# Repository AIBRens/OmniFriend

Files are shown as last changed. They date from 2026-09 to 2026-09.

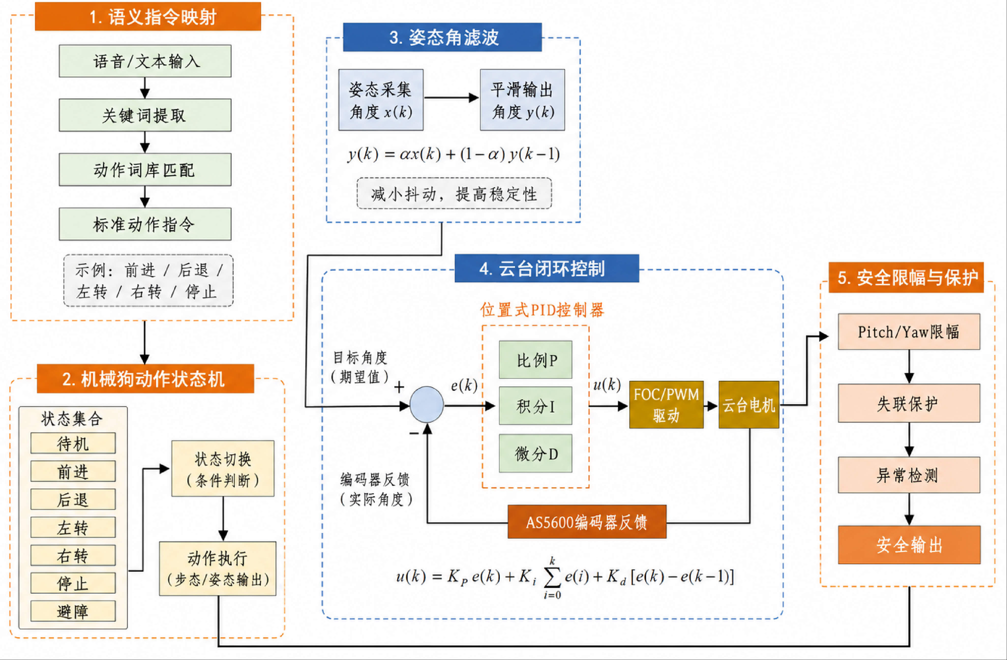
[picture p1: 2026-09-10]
images/18.png

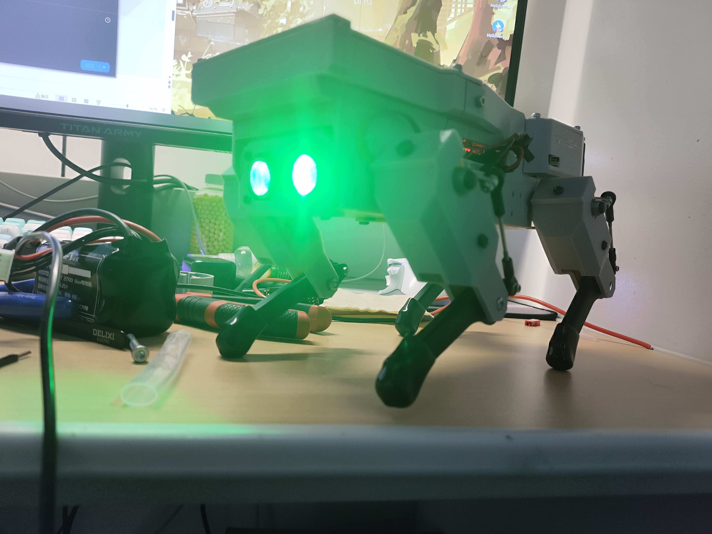
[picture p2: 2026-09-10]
images/20.jpg

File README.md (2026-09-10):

<div align="center">

<!-- <img src="docs/images/logo.png" width="150" alt="全域挚友 Logo"> -->

<h1>全域挚友——语义驱动的多场景微型AI 机械狗</h1>
<h3>机械狗，自动武器站与AI</h3>

<p>本项目基于ESP32与STM32开发。

项目包括：
一个微型的多功能机器狗底盘，并为其接入了云端大模型以实现语音交互。
一个作为机器狗任务模块范例的头瞄式水弹武器站。</p>

<p><b>| 总成本约 ¥1340 | 尺寸约 30cm 级 | 接入云端大模型 | 语音控制 | 公里级远程遥控 | 头部追踪 |</b></p>

<!-- 徽章区域 -->





<br>



</div>

## 📖 目录

- [项目速览](#项目速览)
- [总体设计方案分析](#总体设计方案分析)
- [主要部分实现原理](#主要部分实现原理)
- [硬件设计](#硬件设计)
- [软件设计](#软件设计)
- [调试与优化](#调试与优化)
- [团队分工](#团队分工)
- [局限与后续](#局限与后续)
- [免责声明](#免责声明)
- [致谢与参考](#致谢与参考)
- [器件列表](#器件列表)

## 🎯 项目速览

- **项目定位**：低成本、可扩展、自然交互的微型 AI 机械狗平台
- **核心能力**：语音对话、自然语言指令、四足运动、超声波测距、头戴姿态跟随、第一视角图传、水弹发射
- **硬件架构**：ESP32-S3（AI交互核心）+ ESP32（机械狗主控）+ STM32F103（头瞄端主控）+ STM32F405（武器站主控）
- **通信方式**：WiFi /蓝牙/ UART / NRF24L01 2.4G 无线/5.8G 无线
- **控制算法**：基于C/C++的动作状态机、一阶低通滤波、PID 位置闭环、FOC 无刷电机控制等

---

## ✨ 总体设计方案分析
	
&emsp;&emsp;本设计由机械狗运动系统、AI 交互系统、姿态采集系统、视频图传系统、云台炮塔跟随系统和无线通信系统组成。由于系统中同时存在多个单片机、多个传感器、多个执行机构以及软件上的算法和兼容协调问题，因此其控制特点体现在多模块协同、实时性要求较高、供电负载变化较大和调试过程较复杂几个方面。<br>
本系统的设计思路如下：<br>
1）通过ESP32-S3 语音开发板采集使用者语音，并利用WiFi 与云端大语言模型进行连接，使机械狗能够完成语音对话和自然语言指令解析，为其他功能的控制奠定基础以及实现与人的交流互动；<br>
2）通过机械狗本体ESP32 主控板接收ESP32-S3 下发的动作指令，结合MCP 服务，根据指令内容控制机械狗执行前进、后退、测距、开火等所具有的动作，统一了代码接口，新的硬件功能也容易加入进来；<br>
3）通过头戴式姿态采集端获取操作者头部姿态角，结合PID 算法与其他器件的控制，实现云台的平滑跟随，让武器端可以自由控制；<br>
4）通过3D 打印结构件和模块化安装方式，将机械狗本体与云台扩展模块结合起来，构成一个能够运动、交互和观察的综合平台，实现复杂连贯的功能。<br>

&emsp;&emsp;对于该项目而言，系统使用的核心模块较多，且执行机构包括多路总线舵机和两轴无刷云台电机，因此对供电性能有较高要求。机械狗在启动、转向或快速改变姿态时，舵机会产生较大的瞬时电流；云台电机在快速跟随时也需要稳定的电压输入。如果供电能力不足，可能会造成舵机复位、单片机掉电、无线通信中断或云台抖动等问题。因此，在硬件设计中需要对主控、舵机和云台部分进行分路供电，并保证共地连接可靠。<br>
&emsp;&emsp;控制性能上，机械狗本体动作需要具有一定的稳定性，语音指令下发后不能出现明显延迟或误动作；姿态跟随云台需要具有较好的实时性和连续性，避免因数据丢包、传感器漂移或控制参数不合适而出现跳变和震动。由于经济限制，本项目为可拓展与硬件升级的雏形，主要保证基本功能完整、动作过程稳定、模块之间通信可靠、整体结构便于展示和维护。<br>
&emsp;&emsp;
	
```mermaid
flowchart LR
  User[用户语音] --> S3[ESP32-S3 AI 交互端]
  S3 -->|WiFi| Cloud[云端 ASR / LLM / MCP]
  Cloud -->|结构化指令| S3
  S3 -->|UART| ESP32[机械狗本体 ESP32]
  ESP32 --> Servo[串行总线舵机]
  ESP32 --> Sonar[超声波测距]
  Head[头戴端 STM32F103 + ICM-20948] -->|NRF24L01| Turret[云台端 STM32F405]
  Turret --> Motor[4015 无刷电机 + AS5600]
  Cam[图传摄像头] --> Goggles[图传接收屏]
  S3 -->|UART| Turret
``` 
---

## 🏗️ 主要部分实现原理
1.**语义驱动控制**<br>
&emsp;&emsp;语义驱动控制部分主要完成“语音输入—语义理解—工具调用—指令生成—动作执行”的过程。与传统机器人依赖固定按键或预设命令不同，本课题希望使用者能够通过较自然的语言与机械狗进行交互。例如，当使用者说出“向前走一点”“停下来”“转过去看看”或“点点头”等口语化表达时，系统能够从语句中提取动作意图，并将其转换为机械狗底层可以识别和执行的控制命令，从而实现较自然的人机交互。<br>
&emsp;&emsp;本系统采用ESP32-S3 作为AI 语音交互终端。ESP32-S3 首先通过麦克风采集语音信号，并在本地完成唤醒、音频数据整理等基础处理。唤醒成功后，系统通过WiFi 将音频上传至云端服务，由语音识别模块完成语音转文本，再由大语言模型对文本语义进行理解。为了使模型不仅能够“听懂”用户的话，还能够进一步调用设备功能，系统在初始化联网时会通过MCP（ModelContext Protocol）机制，将已注册的工具信息同步给云端模型。这样，当模型识别到“点头”“前进”“左转”等动作意图时，就不只是返回普通文本回答，而是能够结合上下文判断当前请求属于某个可调用工具，并生成对应的结构化控制结果。<br>
&emsp;&emsp;执行过程中，云端模型根据MCP 提供的工具描述，将自然语言请求映射为底层动作参数，例如把“向前走”映射为FORWARD，把“向左转”映射为LEFT，把“停下”映射为STOP，把“点点头”映射为对应的动作编号或控制字段。ESP32-S3 接收到云端返回的结构化结果后，再通过UART 串口将指令发送给机械狗本体ESP32 主控。ESP32 主控收到数据后，首先对数据帧格式进行校验，然后根据动作字段切换机械狗当前的运动状态或执行对应动作。动作执行完成后，机械狗还可以将当前状态或异常信息回传给ESP32-S3，并通过扬声器或显示模块进行反馈，形成“语音输入—语义理解—动作执行—状态反馈”的闭环控制流程。<br>


2.**武器站云台跟随**<br>
&emsp;&emsp;云台的核心是姿态跟随（PID 算法），主要完成“头部姿态采集—无线数据传输—云台角度跟随”的过程。该模块采用分体式结构，头戴控制端由操作者佩戴，负责采集头部姿态；云台执行端安装在机械狗上方，负责根据接收到的角度数据完成方向跟随。该设计的优势在于操作方式直观，使用者不需要通过摇杆控制两个轴的角度，只需要转动头部即可改变云台指向。<br>
&emsp;&emsp;头戴端使用ICM-20948 九轴姿态传感器获取姿态信息。传感器内部包含陀螺仪、加速度计和磁力计，可以采集角速度、加速度和地磁方向等数据。通过I2C 接口读取传感器数据，姿态解算得到偏航角和俯仰角。为减少每次上电时初始佩戴姿态不同带来的误差，程序设置了零点校准步骤，即将系统启动后的初始头部方向作为基准方向，之后计算相对于基准方向的角度变化。<br>
&emsp;&emsp;姿态数据经过处理后，由NRF24L01 无线模块发送至云台端。该模块工作在2.4G 频段，体积小、成本低、通信速度较快，适合在课程设计模型中实现短距离无线数据传输。为了提高通信稳定性，发送端将角度数据打包成固定长度数据帧，接收端对帧头、帧尾和数据范围进行判断，避免错误数据直接进入控制环节。云台执行端使用STM32F405RGT6 作为主控，结合无刷云台电机和AS5600 磁编码器实现闭环控制。磁编码器能够提供电机轴的角度反馈，主控将目标角度与实际角度进行比较，根据误差输出控制量，使电机逐渐转动到目标位置。与普通舵机相比，无刷云台电机运行更平滑，机械回差较小，更适合完成连续的姿态跟随演示。<br>

3.**整体方案**<br>
&emsp;&emsp;本项目采用“机械狗主体+ 功能扩展模块”的总体设计方案。机械狗本体作为系统的主要移动平台，负责完成运动执行和模块承载；ESP32-S3 AI 交互模块作为上层控制入口，负责语音采集、网络连接、云端转发、语义解析结果接收以及语音反馈；头戴端作为姿态输入设备，负责采集操作者头部的偏航角和俯仰角，图传设备和头戴端可合二为一；云台端作为扩展执行模块，负责根据姿态数据完成两轴跟随和观察方向调整。各部分既可以独立调试，又能够通过串口通信、无线通信和机械结构连接组合成完整系统，从而形成一个具有语音交互、运动控制和姿态跟随能力的微型AI 机械狗平台。<br>
&emsp;&emsp;供电上，机械狗本体采用3S 锂电池作为主要动力来源，并通过降压模块分别为主控板、舵机和外围传感器供电。由于串行总线舵机在启动、转向和姿态调整时会产生较大的瞬时电流，如果主控和舵机共用不稳定电源，容易导致单片机复位或通信异常，因此本项目在设计时将主控供电与舵机供电分开处理，并保证各模块之间可靠共地。ESP32-S3 语音模块采用独立稳压供电，以保证WiFi 通信、语音采集和音频播放过程的稳定性。云台模块则采用独立主控和独立供电方案，使其能够在不影响机械狗运动系统的情况下单独完成调试与优化。<br>
&emsp;&emsp;通信上，ESP32-S3 与机械狗主控之间采用UART 串口通信。ESP32-S3 在接收到云端模型返回的结构化动作指令后，通过TX/RX 引脚将指令发送给机械狗主控，机械狗主控再根据指令字段调用对应的动作函数。该方式连接简单、延迟较低、调试直观，适合课程设计中的功能验证。头戴端与云台端之间采用NRF24L01 无线通信，避免操作者与机械狗之间受到线缆限制。云台端内部通过I2C 接口读取AS5600 磁编码器的角度反馈，并结合无刷电机驱动与FOC 控制算法实现位置闭环，使云台能够较平滑地跟随操作者头部姿态变化。<br>
&emsp;&emsp;结构设计上，机械狗主体和扩展外壳主要采用3D 打印方式制作。该方式成本较低，修改灵活，便于根据PCB 尺寸、屏幕位置、接口开孔和线束走向进行多次调整。云台模块通过螺钉固定在机械狗背部扩展位置，与本体之间保持相对独立，后期可以根据需要拆下或替换为其他功能模块，如机械臂、照明模块、红外测温模块或环境检测模块。这样的设计体现了课程设计中“先实现基础功能，再进行模块扩展”的思路，也为后续进一步集成视觉识别、环境感知和自主任务执行提供了硬件基础。<br>


----------

## 🔧 硬件设计
&emsp;&emsp;硬件设计是本项目能够实现功能的基础，是作品的骨架和支撑。根据系统功能划分，硬件部分主要包括机械狗本体硬件、AI 语音交互硬件、头戴姿态采集硬件、图传硬件、云台执行硬件、无线通信硬件和供电硬件。器件选型时主要考虑成本、体积、性能、资料完整程度以及调试难度，尽量选择常用、资料较多、便于购买和维护的模块。<br>

1.**机械狗本体设计**<br>
&emsp;&emsp;机械狗本体是整个系统的移动平台，主要由3D 打印结构件、舵机、主控板、电池、传感器以及连接线束组成。机械结构部分采用3D 打印方式制作，能够根据舵机尺寸和安装孔位进行灵活设计。机身中部预留电池仓和控制板安装位置，四条腿分别由多个舵机构成，通过舵机角度变化实现腿部摆动和支撑。<br>
&emsp;&emsp;机械狗运动主控采用ESP32 控制板。ESP32 资料丰富，外设接口较多，并支持串口通信、定时器控制、I2C 传感器读取和动作状态机运行等功能，能够满足机械狗本体运动控制需求。主控板接收来自ESP32-S3 的动作指令后，根据预设步态表或运动函数控制各关节舵机转动，实现前进、后退、左转、右转和停止等基本运动动作。<br>


&emsp;&emsp;执行机构采用串行总线舵机。总线舵机相比普通PWM 舵机具有接线简单、控制精度较高、可读取反馈信息等优点。多个舵机可以通过同一条总线串联，减少机身内部线束数量，使机械狗内部结构更加整洁。调试时可以分别设定每个舵机的ID 和初始角度，保证四条腿在初始状态下姿态一致。<br>
&emsp;&emsp;AI 语音交互硬件以ESP32-S3 开发板为核心。ESP32-S3 集成WiFi 和蓝牙功能，并具有较强的音频处理和边缘计算能力，适合用于语音采集、网络通信和简单的人机交互任务。语音输入部分采用I2S 数字麦克风，能够获得较清晰的语音信号；语音输出部分采用功放模块和小型扬声器，用于播放系统回复和动作反馈。自主画电路板将芯片与一些就基础模块集成便于后续的模块化开发。<br>


&emsp;&emsp;环境感知方面，机械狗前部设置超声波测距模块，用于检测前方障碍物距离。当机械狗在前进过程中检测到距离过近时，主控可以执行停止或转向动作，避免直接碰撞。机身内部还可以安装MPU6050 等惯性测量模块，用于获取机体俯仰等变化，为姿态稳定和运动补偿提供数据基础。<br>


2.**头戴控制端设计**<br>
&emsp;&emsp;头戴控制端的设计重点是轻量化、低功耗和佩戴方便。该端主要由STM32F103C8T6 最小系统板、ICM-20948 九轴姿态传感器、NRF24L01 无线模块、电池和电源升压模块组成。各模块体积较小，可以安装在头戴支架或小型盒体中，使用时由操作者佩戴在头部。STM32F103C8T6 负责读取姿态传感器数据，并将数据进行滤波、零点校准和打包发送。ICM-20948 能够输出加速度、角速度和磁场数据，为姿态解算提供基础。由于传感器原始数据存在噪声和漂移，程序中需要对数据进行简单滤波，并设置启动校准过程，使系统在不同佩戴角度下都能获得相对稳定的姿态变化量。<br>
&emsp;&emsp;无线通信模块采用NRF24L01+PA+LNA。该模块带有功放和低噪声放大电路，通信距离和抗干扰能力优于普通NRF24L01 模块。头戴端只需要将姿态角数据单向发送至云台端，因此通信协议可以设计得较为简单，只需保证帧格式固定、数据范围合理即可。



| 器件类别 | 具体型号 | 功能说明 |
| :--- | :--- | :--- |
| 主控芯片 | STM32F103C8T6 | 负责传感器读取、姿态角处理和无线发送 |
| 姿态传感器 | ICM-20948 | 采集头部加速度、角速度和磁场信息 |
| 无线通信 | NRF24L01+PA+LNA | 将姿态角数据发送至云台执行端 |
| 供电模块 | 18650 电池及升压板 | 为头戴端提供独立电源 |
| 结构支架 | 3D 打印头戴支架 | 固定传感器和主控，方便佩戴与调试 |

3.**武器站设计**<br>
&emsp;&emsp;武器站部分的硬件均为自主建模与3D 打印，主要由头戴控制端和云台执行端组成。头戴控制端负责采集操作者头部姿态，云台执行端负责根据姿态数据完成方向跟随。该部分采用独立供电、独立通信和独立控制方式，不影响机械狗本体的基本运动功能。该端主要由STM32F405RGT6主控、无刷云台电机、FOC 驱动板、AS5600 磁编码器、NRF24L01 接收模块和图传模块组成。STM32F405RGT6 具有较高主频和浮点运算能力，能够满足姿态数据解析、编码器读取和闭环控制计算等需求。<br>
&emsp;&emsp;执行电机选用4015 无刷云台电机。该类电机具有转动平滑、噪声较低、力矩输出连续等优点，适合用于摄像头云台和姿态跟随平台。为了获得电机实际角度，系统在电机轴端安装AS5600磁编码器。AS5600 能够输出绝对角度信息，主控通过I2C 接口读取该角度，与目标角度进行比较后输出控制量。<br>
&emsp;&emsp;云台端还搭载5.8G 图传模块（可分离），用于传输第一视角画面。图传系统能够使操作者从云台视角观察前方环境，与头部姿态跟随功能结合后，可以形成较直观的“看向哪里，画面转向哪里”的演示效果。由于图传模块对电源稳定性有一定要求，因此在供电设计中应与电机驱动部分做好隔离和滤波，减少电机动作对画面的干扰。<br>


| 器件类别 | 具体型号 | 功能说明 |
| :--- | :--- | :--- |
| 主控芯片 | STM32F405RGT6 | 负责无线接收、数据解析和云台闭环控制 |
| 无刷驱动 | 灯哥开源 V3P 驱动 | 驱动无刷云台电机，实现 FOC 控制 |
| 执行电机 | 4015 无刷云台电机 | 完成云台偏航和俯仰两个方向的转动 |
| 位置编码 | AS5600 磁编码器 | 提供电机轴角度反馈，构成闭环控制 |
| 视频图传 | 5.8G 图传模块 | 传输第一视角画面，方便远程观察演示 |
| 供电模块 | 降压稳压模块 | 为主控、驱动和图传模块提供稳定电压 |

----------

## 💻 软件设计
   &emsp;&emsp;软件部分决定了各个硬件模块能否稳定协同工作。根据功能划分，软件设计主要包括机械狗AI 交互、头戴端控制、云台武器端控制以及无线通信。软件整体采用分层设计思想，上层负责语义交互和任务判断，下层负责具体动作控制和执行机构驱动，两者分别完成用通信协议连接起来。<br>
    1. **AI 交互**<br>
&emsp;&emsp;AI 交互部分是本课题智能的核心。接入AI 小智大模型到ESP32-S3 上，设置MCP 服务，语言交互以及调用控制已有的所有功能。<br>
&emsp;&emsp;程序运行后，ESP32-S3 首先进入待唤醒状态，持续监听外部声音。当检测到设定唤醒词后，系统开始录制语音，并将音频数据整理为云端接口可以接收的格式。音频上传后，云端服务完成语音识别和语义理解，并返回对应文本或结构化指令。对于聊天类问题，ESP32-S3 直接将返回内容通过语音合成模块播放出来；对于动作类指令，ESP32-S3 则提取其中的动作字段，并通过串口发送给机械狗本体ESP32 主控。<br>
&emsp;&emsp;为了减少自然语言带来的不确定性，程序中预先设置了动作关键词和标准指令之间的对应关系。例如，“前进、往前走、向前移动”均对应前进指令；“停下、停止、别动”均对应停止指令；“左转、向左看、往左转”均对应左转指令。这样可以提高识别成功率，也可以避免大语言模型返回过长文本导致底层主控难以解析。<br>
&emsp;&emsp;ESP32-S3 与机械狗本体ESP32 之间采用简单串口协议通信。每一条动作指令由帧头、指令字、参数位和校验位组成。帧头用于判断一条数据的开始，指令字用于表示动作类型，参数位用于表示持续时间或动作幅度，校验位用于判断传输是否正确。机械狗本体ESP32 接收到数据后，根据指令内容进入相应状态，并在动作完成后返回执行结果。ESP32-S3 再根据返回结果进行语音提示，如“已前进”“已停止”“前方有障碍”等。<br>

2.**头戴端控制**<br>
&emsp;&emsp;头戴端控制部分负责完成姿态数据采集、姿态解算和无线发送。程序启动后，STM32F103C8T6首先完成ICM-20948 和NRF24L01 模块初始化，通过ICM-20948 获取头部加速度、角速度等数据，并利用内部DMP 完成姿态解算，将四元数转换为偏航角和俯仰角。由于不同操作者佩戴角度存在差异，系统启动时会进行零点校准，将当前状态作为参考方向，后续只计算头部相对变化量。<br>
&emsp;&emsp;处理后的姿态数据经过简单滤波后，通过NRF24L01 无线发送至云台端。为了降低通信延迟，数据帧仅包含偏航角、俯仰角和校验信息，并采用固定格式传输。当出现异常数据或通信中断时，程序会进行数据判断，避免错误角度直接影响云台运动，提高系统稳定性。<br>

3.**云台武器端控制**<br>
&emsp;&emsp;云台武器端负责姿态数据接收、角度解析和闭环控制。STM32F405RGT6 接收到头戴端发送的数据后，对目标角度进行解析和滤波，并结合AS5600 磁编码器获取电机实际角度，通过比较目标角度与反馈角度之间的误差，实现云台位置闭环控制。<br>
&emsp;&emsp;执行机构采用两台4015 无刷云台电机，通过FOC 算法控制偏航和俯仰两个方向转动。相比普通舵机，无刷电机具有运行平滑、响应速度快等特点，更适合连续姿态跟随。控制过程中加入PID 调节和角度限幅，减少电机震荡和机械冲击，使云台能够稳定完成“人看哪里，云台转向哪里”的跟随效果。<br>
&emsp;&emsp;其中武器的开火设定为高电平下连续开火，也就是通过控制电平可以实现全自动开火，收到的云台芯片指令即为简单的电平信号。<br>
4.**无线通信**<br>
&emsp;&emsp;无线通信部分主要用于头戴端和云台端之间的姿态数据传输。由于姿态跟随对实时性有一定要求，因此数据帧需要尽量简洁，通信过程需要尽量稳定。头戴端将偏航角和俯仰角转化为整型数据后发送，云台端接收到数据后再恢复为角度值，并作为云台控制目标。<br>
&emsp;&emsp;头戴端程序的主要流程为：初始化STM32 外设、初始化ICM-20948、初始化NRF24L01、进行姿态零点校准、循环读取姿态数据、进行滤波处理、打包发送数据。由于头部姿态变化较为连续，发送数据时不需要包含过多信息，只需发送偏航角、俯仰角和简单校验即可，这些数据发送给云台端。<br>
&emsp;&emsp;云台端程序的主要流程为：初始化STM32F405、初始化NRF24L01、初始化AS5600 编码器、初始化FOC 驱动参数、等待接收姿态数据、判断数据是否有效、对目标角度进行限幅和滤波、执行闭环控制。若一段时间内未接收到头戴端传来的有效数据，云台端会保持当前角度或缓慢回到安全位置，避免因通信中断造成异常动作。在实际调试中，无线通信容易受到实验室WiFi、蓝牙设备和电源噪声甚至电磁干扰等影响。<br>
&emsp;&emsp;为提高系统稳定性，程序中加入了数据有效性判断和异常跳变抑制。当接收到的数据超出合理范围，或相邻两帧角度变化过大时，接收端不会立即执行该数据，而是将其视为异常帧丢弃。这样可以减少丢包或误码造成的云台突然跳动。<br>

5.**算法设计**<br>
&emsp;&emsp;算法主要包括语义指令映射、机械狗动作状态机、姿态角滤波算法、云台PID 闭环控制算法和安全限幅算法。虽然这些都不是复杂的算法，但它们直接影响系统运行效果，是课程设计中非常重要的部分。<br>
1）语义指令映射算法。语音识别得到的文本往往不是固定格式，因此需要将自然语言中的关键词提取出来，并映射成ESP32 能够识别的标准动作。程序中建立动作词库，将相近表达归为同一类动作。例如“向前走”“前进一下”“往前移动”都映射为FORWARD；“停下”“暂停”“不要动”都映射为STOP。通过这种方式，系统能够适应一定程度的口语表达。<br>
2）机械狗动作状态机。机械狗的动作不应由单个瞬时指令直接控制，而应由状态机进行管理。系统设置待机、前进、后退、左转、右转、避障、停止等状态。每个状态对应一组舵机角度变化规律。当主控接收到新指令时，先判断当前状态是否允许切换，再执行对应动作。这样可以避免机械狗在动作未完成时突然切换导致姿态不稳。<br>
3）姿态角滤波算法。姿态传感器采集到的数据会受到手部抖动、传感器噪声和零漂影响，如果直接用于云台控制，会导致云台持续轻微抖动。因此程序中采用一阶低通滤波对目标角度进行平滑处理，其形式如下：

$$
y(k) = \alpha x(k) + (1-\alpha)y(k-1) \quad (1)
$$

式中，\(x(k)\) 为当前采集角度，\(y(k)\) 为滤波后角度，\(\alpha\) 为滤波系数。\(\alpha\) 越大，响应越快但抖动越明显；\(\alpha\) 越小，输出越平滑但跟随会变慢。实际调试时需要根据云台响应情况选择合适参数。

4）云台闭环控制算法。云台控制采用位置闭环思想，将目标角度与编码器反馈角度进行比较，根据误差输出控制量。基本 PID 控制公式如下：

$$
u(k) = K_p e(k) + K_i \sum_{j=0}^{k} e(j) + K_d \big[e(k)-e(k-1)\big] \quad (2)
$$

其中，\(e(k)\) 表示当前角度误差，\(K_p\)、\(K_i\)、\(K_d\) 分别为比例、积分和微分系数。比例项决定系统响应速度，积分项用于消除稳态误差，微分项用于抑制变化过快带来的超调。在本项目中，为了减少云台抖动，积分项不宜设置过大，同时需要配合死区控制。

5）安全限幅算法。为了避免云台转动角度过大造成线材缠绕或结构干涉，程序中设置了角度限幅。当目标角度超过最大允许范围时，系统自动将其限制在边界值内。同时，当检测到连续异常数据或通信中断时，云台不继续执行新目标，而是保持当前位置。该算法虽然简单，但能有效提高系统安全性和稳定性。



----------
## 🐛 调试与优化
&emsp;&emsp;系统调试过程中，团队主要遇到了语音识别不稳定、舵机动作不协调、无线通信丢包、云台零点抖动和机械结构干涉等问题。通过逐步排查和修改程序，系统运行稳定性得到明显改善。<br>
1）本地MCP 指令解析问题。初期测试时，ESP32-S3 能够完成语音识别，但大语言模型返回的内容较长，有时包含解释性文字，导致机械狗本体ESP32 无法直接识别动作指令。针对该问题，团队在ESP32-S3 端增加了关键词提取和指令映射步骤，只将标准动作指令发送给ESP32，而不是将完整回复发送到底层主控。另外，流行的几种MCP 方案均为两芯片连接至同局域网的方案，这种办法不稳定，并且实现起来复杂，要配置各种环境，于是本作品采取本地的MCP 方案，让大模型对功能的调用执行通过物理跳线实现。这样既保留了对话功能，又保证了动作控制的可靠性。<br>
2）机械狗站立姿态偏斜问题。在本体调试过程中，机械狗有时会出现站立不平稳或行走时向一侧偏移的现象。经过检查发现，主要原因是部分舵机初始角度不一致，且左右腿结构安装存在细小误差。解决方法是重新标定每个舵机中位值，并在程序中为不同关节设置角度补偿。调整后，机械狗站立姿态更加稳定，前进时偏移现象有所减轻。<br>
3）供电瞬态压降问题。机械狗多个舵机同时动作时，电流需求会瞬间增大，曾出现主控板复位和语音模块重启的情况。针对该问题，团队将主控供电和舵机供电分开，增加降压模块余量，并在电源输入端增加滤波电容。分路供电后，机械狗连续动作时系统稳定性明显提高。<br>
4）无线通信丢包与角度跳变问题。在实验室环境中，NRF24L01 偶尔会受到其他2.4G 设备影响，导致接收端数据短时间异常。若异常数据直接用于控制，云台会出现突然跳动。针对该问题，程序中加入数据范围判断和角度变化率判断。当单帧数据变化过大时，系统先判断为异常帧并丢弃；只有连续多帧数据变化趋势一致时，才认为操作者确实进行了快速转头动作。<br>
5）云台零点微震问题。静态测试中，当操作者头部保持不动时，云台仍可能出现轻微抖动。分析原因主要是姿态传感器存在微小噪声，编码器反馈也有一定波动，导致控制器不断进行小幅修正。解决方法是在角度误差较小时加入控制死区，当误差小于设定阈值时，控制器不再输出明显修正量，同时适当降低PID 参数中的比例和积分系数，使云台在静止状态下更加平稳。<br>
6）机械结构重心与干涉问题。云台在俯仰角度较大时，部分结构件可能与机械狗背部平台或图传摄像头线材发生干涉。针对该问题，一方面在程序中加入角度限幅，限制云台最大俯仰角和偏航角；另一方面对3D 打印支架进行修改，增加线材固定点和转动空间。经过调整后，云台在正常演示角度内能够较顺畅地转动。<br>
经过多轮调试后，系统基本实现了预定功能。机械狗可以在平整地面完成基本移动动作，ESP32-S3 可以完成语音交互和动作指令下发，头戴端可以将姿态变化无线发送至云台端，云台能够跟随操作者头部方向进行转动。虽然系统距离成熟产品还有一定差距，但作为小型项目，已经较完整地体现了智能交互、嵌入式控制和模块化机器人的设计思路。<br>


## 👥 团队分工

&emsp;&emsp;我：部件选型与采购；硬件设计与建模；PCB设计；多单片机协作的设计与开发；滤波与PID算法的开发；与武器站、头戴端相关程序的编写与调试；硬件装配与测试。<br>
&emsp;&emsp;我的另一位队友：云端大模型与各模块的接入与通信工作；大模型的配置、提示词处理与工具调用；配置UART通信；与AI、超声波测距相关程序的编写。<br>

----------

## 🔭 局限与后续

&emsp;&emsp;对于本项目，我们已经实现了语音交互、机械狗基础动作、姿态跟随、武器全自动开火、无线通信等功能，具有多方协调与初具只能的优点，但距离更加智能、稳定的机械狗仍有不少可以继续改进的地方。<br>
首先，机械狗运动稳定性仍有提升空间。当前机械狗能够完成基本运动，但在负载增加、地面不平或连续动作时，机身姿态可能不稳。后续可以引入与优化平衡算法，增加机身姿态反馈，使机械狗能够根据外部反馈数据自动调整腿部动作，提高运动过程中的稳定性。<br>
&emsp;&emsp;其次，AI 交互功能对网络环境仍有一定依赖。当前语音识别和语义理解主要依靠云端服务完成，当网络状态不稳定或距离网源较时，系统响应速度和交互连续性会受到影响。后续可以尝试引入边缘计算小程序，在本地部署轻量化语音识别模型或小型语言模型，使机械狗在离线或弱网环境下也能完成基础交互。<br>
&emsp;&emsp;再次，云台跟随精度和稳定性还可以继续优化。当前云台能够跟随头部姿态变化，但在快速转头或机械狗运动过程中，仍可能出现滞后和抖动。后续可以在滤波算法、控制死区和机身运动补偿方面继续改进，或者引入串级PID，实现更精细的反馈闭环控制，使云台在动态情况等也能保持较稳定。<br>
&emsp;&emsp;此外，视觉系统后续可以增加图像处理模块，结合YOLO、OpenMV 色块识别或轻量化目标检测算法，实现目标识别、人体识别、路线识别和自动巡检等功能。这样机械狗就不只是按照语音指令执行动作，而是能够根据环境信息做出更主动的判断，朝着具身智能迈进一步。<br>
&emsp;&emsp;最后，也是最重要的两个关联点，目前很大的不足是硬件性能不够以及衍生的结构设计缺陷，机械狗主体是ESP32，运算和内存性能都较低，支撑不了较强的处理算法、实时反馈的运动控制，若非原结构与集成的限制，可改用树莓派等板子，利用强化学习而非固定代码让机械狗自己运动以及部署深度学习视觉处理，此时也可以在离线模式下进行AI 交互，而机身与低扭矩的舵机让机械狗承载能力不足，让拓展性受到了限制。<br>

----------

## ⚠️ 免责声明

本项目为课程设计与学习交流用途，发射模块仅用于水弹娱乐演示，安全无害，比动能小于1.8J/cm²。请勿改装为危险装置，请勿对准人或动物，操作时请佩戴护目镜并遵守当地法律法规。<br>

----------

## 🙏 致谢与参考

-   我的另一位团队成员<br>
-   课程指导老师，他一语点醒梦中人，告诉我电机运行会产生电磁干扰，可能是导致I2C总线死锁的原因<br>
- 帮我干活的Gemini，GPT，deepseek和豆包<br>
-  小智AI.Dev<br>
-   Espressif ESP32 / ESP32-S3 官方资料<br>
-   SimpleFOC 开源项目<br>
-   SparkFun ICM-20948 库<br>
-   Anthropic MCP 协议<br>

**参考文献**：<br>
[1] 侯焱彬, 杨永辉, 李志刚, 等. 面向工业气体安全监控的智能巡检机械狗[J]. 工业控制计算机,2026,39(5):63-64+67.<br>
[2] 夏立伟. 四足机械狗在化工安全领域的应用[J]. 石化技术,2025,32(6):348-350.<br>
[3] 潘杰. 基于MCP 智能体架构的“本地-云端大模型协同”优化方案研究[J]. 电脑编程技巧与维护,2026,(2):3-6+11.<br>
[4] 夏峰. 头盔瞄准系统的人机交互研究及设计[D]. 哈尔滨工业大学,2013.<br>
[5] 王云龙, 赵正媛, 吴志林, 等. 轻型遥控武器站多工况力学特性及射击扰动[J]. 兵工学报,2025,46(10):366-380.<br>
[6] 郭丽君, 周文杰, 刘杰, 等. 一种超轻型遥控武器站的设计[J]. 电脑与信息技术,2025,33(4):122-127.<br>
[7] Anthropic. Model Context Protocol Specification[EB/OL]. (2024-11-25)[2026-07-05].https://modelcontextprotocol.io/specification.<br>
[8] Espressif Systems. ESP32 Series Datasheet and ESP32-S3 Series Datasheet[EB/OL]. [2026-07-05]. https://www.espressif.com/en/support/documents/technical-documents.<br>
[9] Nordic Semiconductor. nRF24L01+ Single Chip 2.4GHz Transceiver Product Specificationv1.0[EB/OL]. Nordic Semiconductor, 2008.<br>
[10] TDK InvenSense. ICM-20948 Datasheet[EB/OL]. TDK Corporation, 2016.<br>
[11] Redmon J, Divvala S, Girshick R, Farhadi A. You Only Look Once: Unified, Real-TimeObject Detection[C]//Proceedings of the IEEE Conference on Computer Vision and PatternRecognition. 2016:779-788.<br>
[12] Liao Q, Zhang Z, Ke W, et al. Review of Quadruped Robots for Dynamic Locomotion[J/OL]. arXiv preprint arXiv:2005.11134, 2020.<br>
[13] Mudalige N D W, Van K D, Han J, et al. HyperDog: An Open-Source Quadruped RobotPlatform Based on ROS2 and micro-ROS[J/OL]. arXiv preprint arXiv:2209.09171, 2022.<br>

----------
## 📦 器件列表

| 应用模块 | 器材名称与规格 | 价格（元） |
| :--- | :--- | :--- |
| 云台主控 | STM32F405RGT6 × 2 | 79.60 |
| 云台转接 | DengFOC STM32 转接板 | 40.00 |
| 供弹结构 | 硅胶管 | 3.16 |
| 图传系统 | 图传线 | 12.90 |
| 调试工具 | CH340G 串口调试器 | 6.80 |
| 接口转接 | Type-C 垂直转接头 | 13.50 |
| 无刷驱动 | 灯哥开源双路无刷电机控制板 | 84.00 |
| 发射控制 | 大功率 MOS 管 | 7.26 |
| 云台电机 | 4015 直流无刷电机 × 2 | 231.28 |
| 烧录调试 | ST-Link 烧录器 | 6.79 |
| 云台结构 | 铝合金底座转盘轴承 | 22.70 |
| 供电系统 | 降压板 | 34.80 |
| 图传系统 | 5.8G 天线 | 5.50 |
| 散热系统 | 散热风扇 | 3.25 |
| 电源接口 | XT30 接头 | 13.50 |
| 辅助瞄准 | 激光头 | 11.70 |
| 供电系统 | 电源分路器 | 53.00 |
| 连接材料 | 导线 | 4.88 |
| 云台结构 | 光轴 | 6.08 |
| 姿态采集 | ICM20948 九轴陀螺仪 | 43.00 |
| 发射耗材 | 高抗压加硬水弹 | 3.69 |
| PCB 辅料 | 排针排母、开关、PCB 微型元件等 | 24.85 |
| 无线通信 | NRF24L01+LAN 无线模块 × 2 | 17.92 |
| 紧固件 | 螺丝 | 11.94 |
| 结构制作 | 3D 打印耗材 | 29.00 |
| 图传系统 | 2W 图传 + 1500 线摄像头 | 170.00 |
| 图传接收 | 图传眼罩接收屏 | 289.00 |
| 图传系统 | 图传天线 | 22.46 |
| 发射机构 | 水弹波箱 | 46.40 |
| 发射机构 | 弹匣 | 19.00 |
| 外观装饰 | 模型水贴 | 13.00 |
| 云台结构 | 薄壁轴承 × 4 | 8.84 |
| **项目总造价** | | **1339.80** |

## 📄 License

MIT License，详见 [LICENSE](https://license/)。

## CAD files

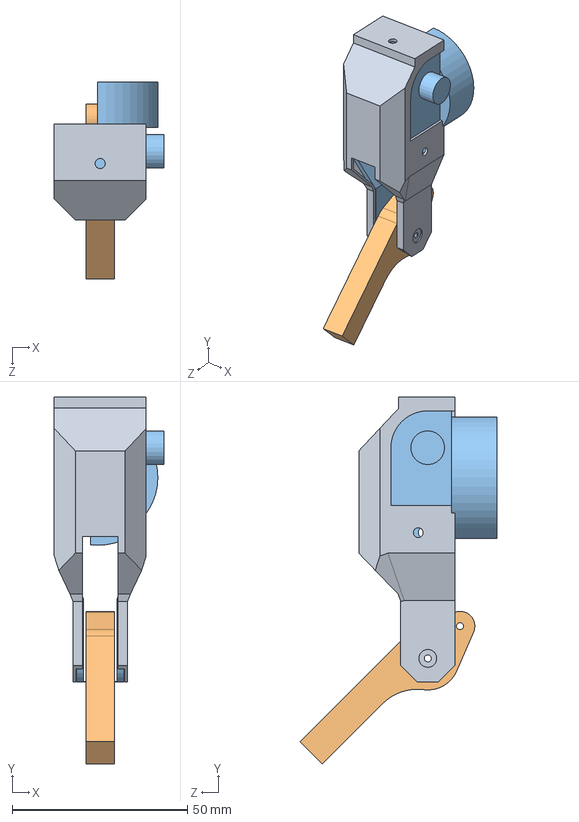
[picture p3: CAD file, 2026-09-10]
DOGV2.0/腿.SLDASM
31.2 x 104.6 x 56.1 mm
大腿
小腿
腿外壳

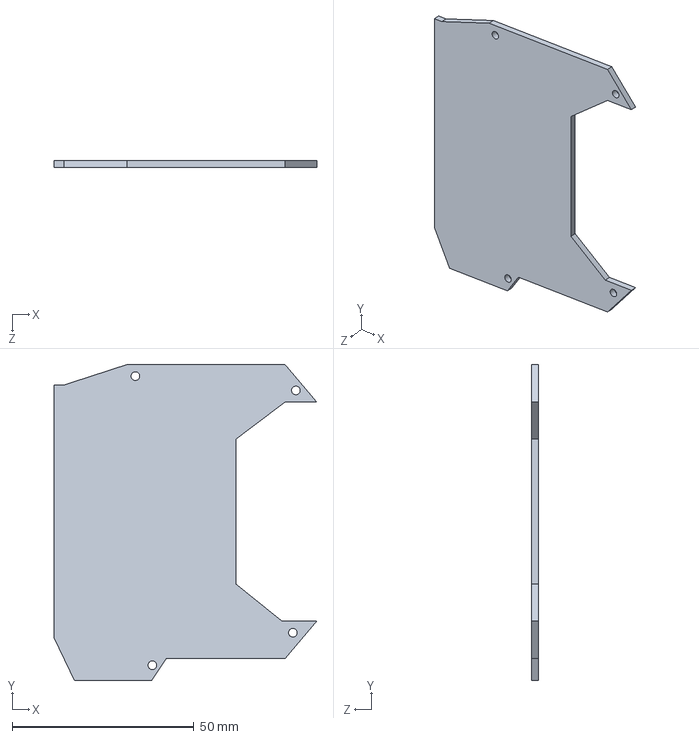
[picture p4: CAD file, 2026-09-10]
DOGV2.0/后上盖.SLDPRT
72.3 x 87.0 x 2.00 mm

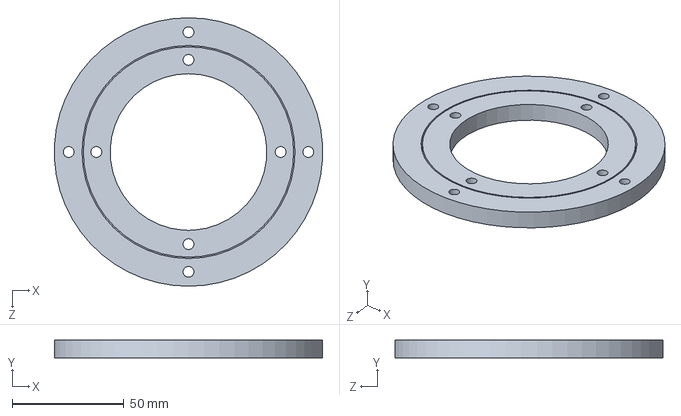
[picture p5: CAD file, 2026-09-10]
吕布骑狗V2.0/转盘.SLDPRT
119.8 x 8.00 x 120.0 mm

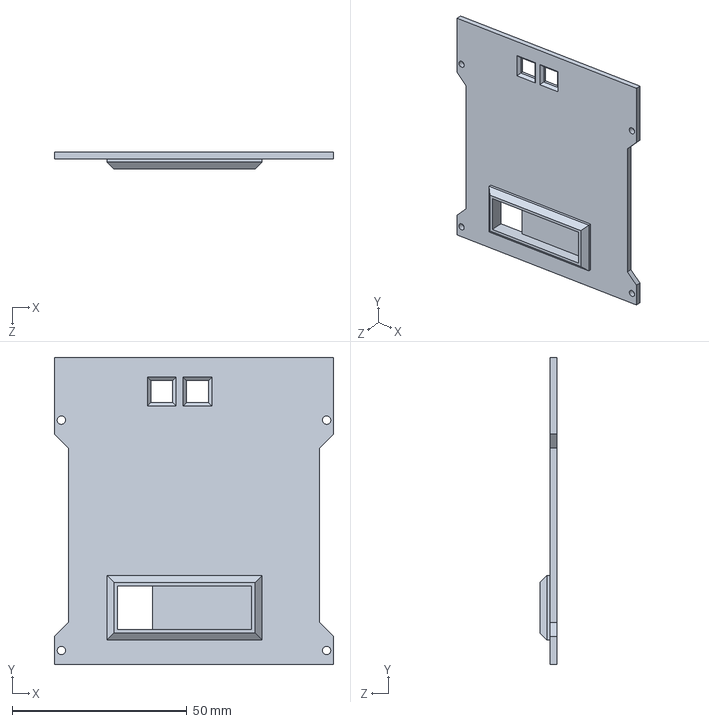
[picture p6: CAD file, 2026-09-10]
DOGV2.0/前盖.SLDPRT
79.8 x 87.7 x 5.00 mm

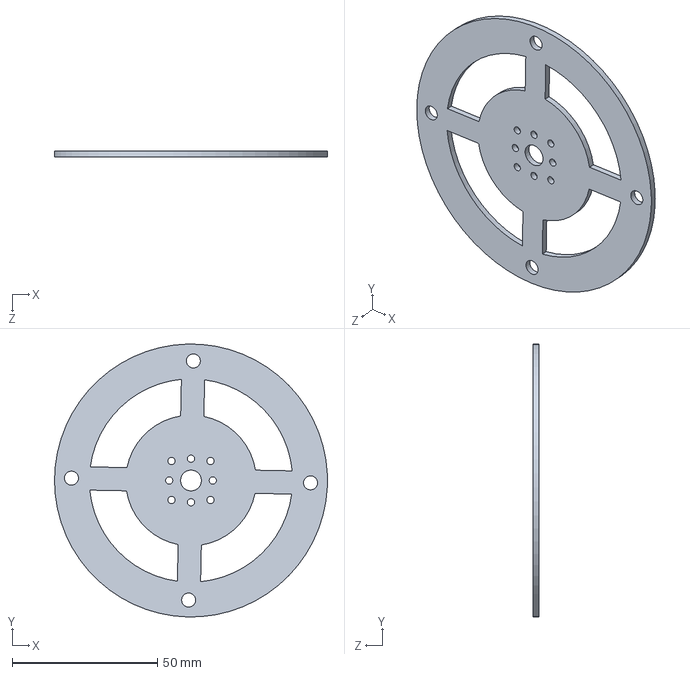
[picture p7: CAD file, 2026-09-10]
吕布骑狗V2.0/底座垫片.SLDPRT
94.0 x 94.0 x 2.00 mm

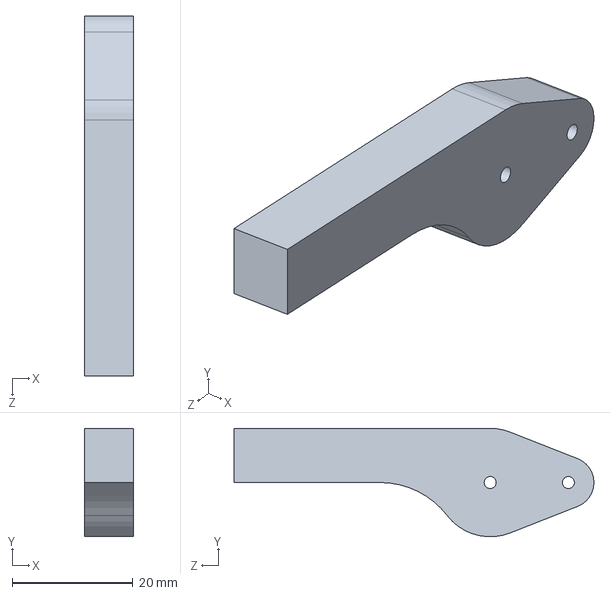
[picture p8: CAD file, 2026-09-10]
DOGV2.0/小腿.SLDPRT
8.13 x 18.0 x 59.8 mm

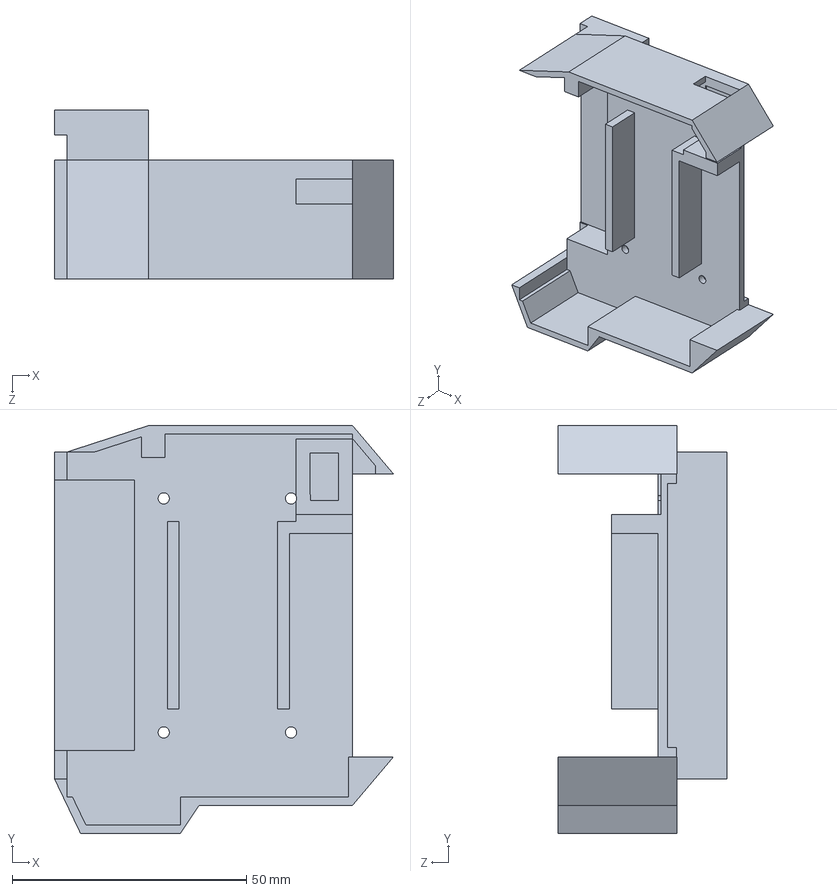
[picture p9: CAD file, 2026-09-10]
DOGV2.0/尾巴.SLDPRT
72.3 x 87.0 x 36.1 mm

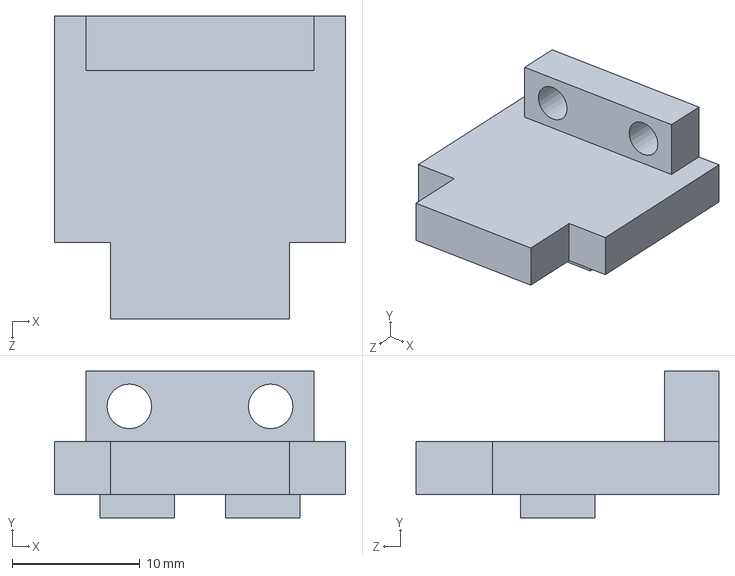
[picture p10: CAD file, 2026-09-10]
吕布骑狗V2.0/弹匣供弹片.SLDPRT
22.8 x 11.5 x 23.8 mm

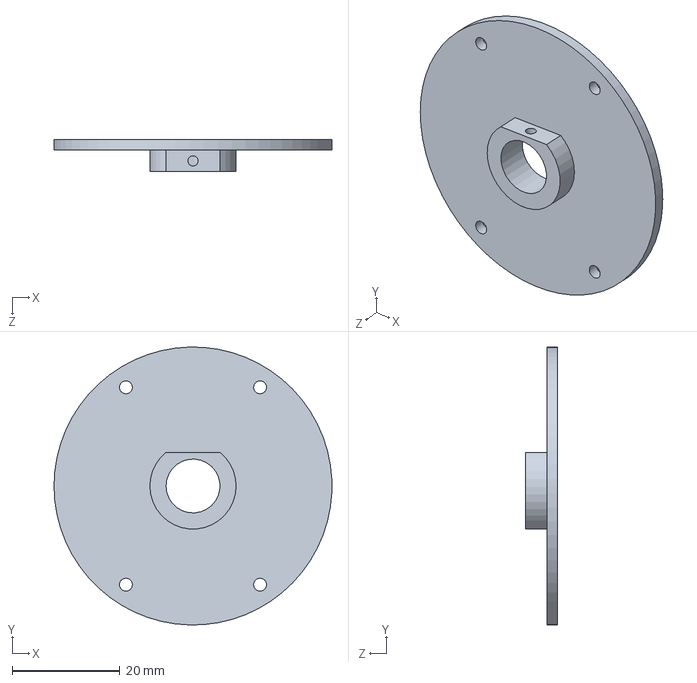
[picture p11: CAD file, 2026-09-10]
吕布骑狗V2.0/传感器室盖子.SLDPRT
51.6 x 51.6 x 6.00 mm

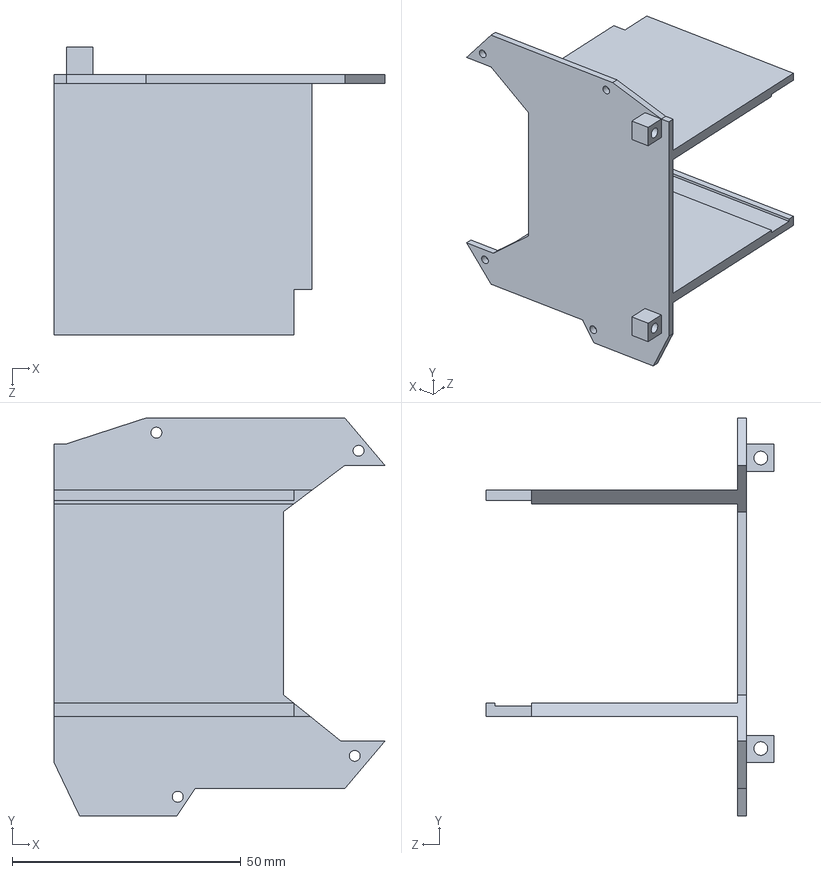
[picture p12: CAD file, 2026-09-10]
吕布骑狗V2.0/后上盖.SLDPRT
72.3 x 87.0 x 63.0 mm

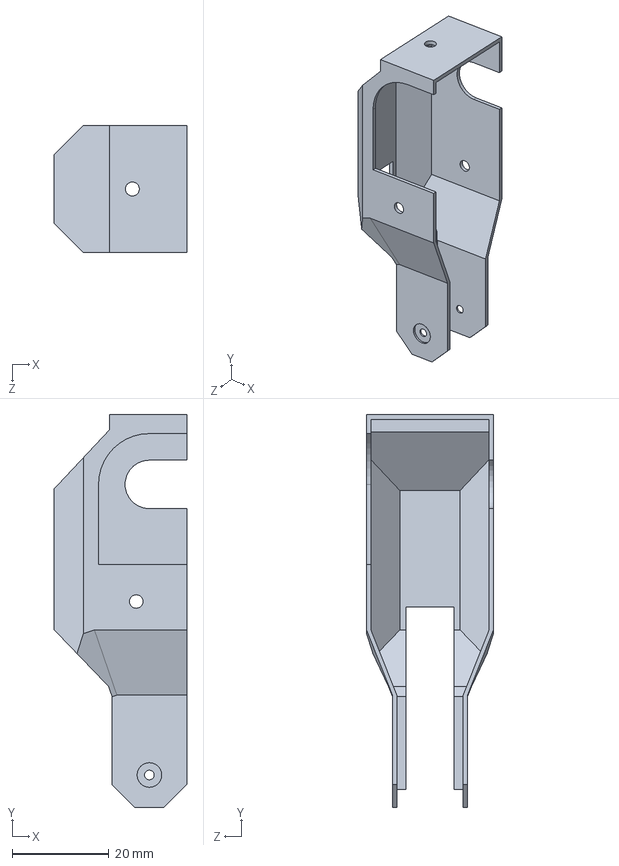
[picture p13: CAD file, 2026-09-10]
DOGV2.0/腿外壳.SLDPRT
27.4 x 81.2 x 26.2 mm

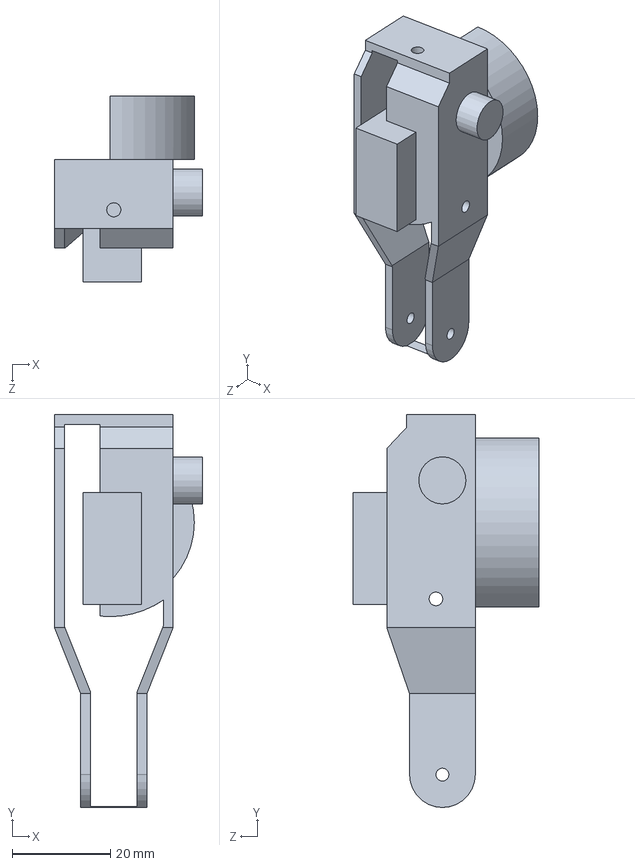
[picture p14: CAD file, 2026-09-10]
DOGV2.0/大腿.SLDPRT
30.2 x 80.2 x 38.0 mm

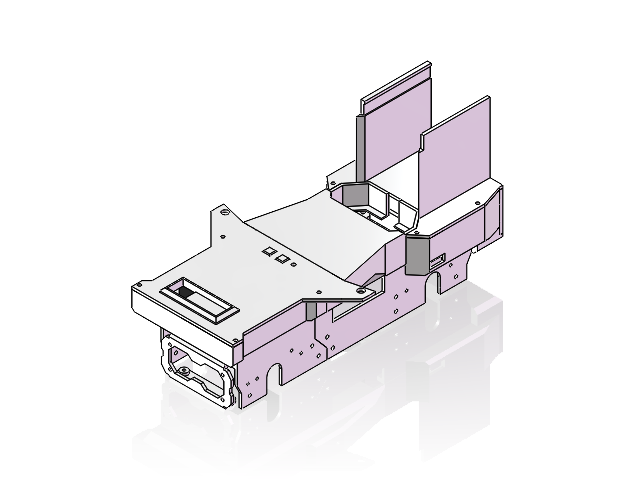
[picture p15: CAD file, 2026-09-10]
吕布骑狗V2.0/总装.SLDASM
前板
超声波框架
板子
音响
电池盒
充电芯片
后框架
尾巴
中部底座
后上盖
按钮 x 2
前盖

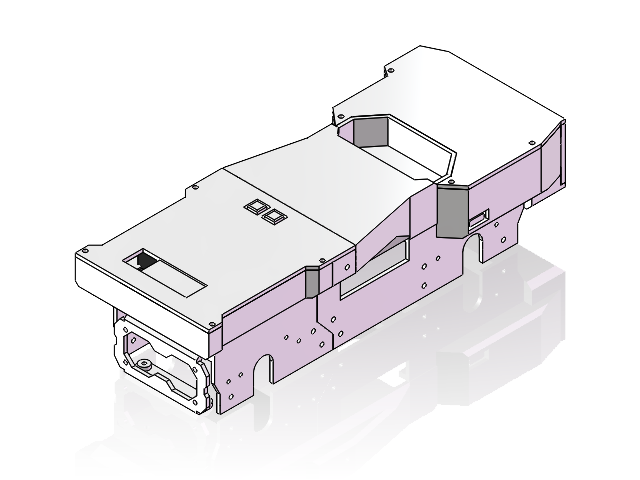
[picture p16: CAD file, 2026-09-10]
DOGV2.0/总装.SLDASM
前板
超声波框架
板子
音响
电池盒
充电芯片
后框架
尾巴
中部底座
后上盖
按钮 x 2
前盖

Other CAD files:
吕布骑狗V2.0/武器站总装.SLDASM
吕布骑狗V2.0/吕布骑狗.SLDASM
DOGV2.0/中部底座.SLDPRT
DOGV2.0/前板.SLDPRT
DOGV2.0/后框架.SLDPRT
DOGV2.0/超声波框架.SLDPRT
吕布骑狗V2.0/217004S电池.SLDPRT
吕布骑狗V2.0/三通垫片.SLDPRT
吕布骑狗V2.0/中部底座.SLDPRT
吕布骑狗V2.0/传感器室.SLDPRT
吕布骑狗V2.0/供弹弯管.SLDPRT
吕布骑狗V2.0/光轴.SLDPRT
吕布骑狗V2.0/前板.SLDPRT
吕布骑狗V2.0/前盖.SLDPRT
吕布骑狗V2.0/右波壳.SLDPRT
吕布骑狗V2.0/后框架.SLDPRT
吕布骑狗V2.0/图传.SLDPRT
吕布骑狗V2.0/天线.SLDPRT
吕布骑狗V2.0/头戴连接支架.SLDPRT
吕布骑狗V2.0/左波壳.SLDPRT
吕布骑狗V2.0/底部支架.SLDPRT
吕布骑狗V2.0/弹匣.SLDPRT
吕布骑狗V2.0/弹匣井盖板.SLDPRT
吕布骑狗V2.0/摄像头.SLDPRT
吕布骑狗V2.0/摇臂支架.SLDPRT
吕布骑狗V2.0/电机.SLDPRT
吕布骑狗V2.0/电源模块.SLDPRT
吕布骑狗V2.0/超声波框架.SLDPRT
吕布骑狗V2.0/轴承.SLDPRT
吕布骑狗V2.0/轴承转接.SLDPRT
吕布骑狗V2.0/通信模块.SLDPRT

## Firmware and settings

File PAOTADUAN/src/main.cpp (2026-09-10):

#include <Arduino.h>
#include <SimpleFOC.h>
#include "nRF24L01_API.h" 

// 强行声明 NRF 函数，防止找不到
extern void NRF24L01_Pin_Init(void);
extern unsigned char NRF24L01_Check(void);
extern void NRF24L01_RX_Init(void);
extern unsigned char NRF24L01_RxPacket(unsigned char *rxbuf);

// [NODE: I2C_INSTANCE_START]
struct MySoftI2C {
  uint8_t sda, scl;
  void init(uint8_t _sda, uint8_t _scl) {
    sda = _sda; scl = _scl;
    pinMode(sda, INPUT_PULLUP);
    pinMode(scl, INPUT_PULLUP);
  }
  void sda_out(bool val) { if(val) pinMode(sda, INPUT_PULLUP); else { pinMode(sda, OUTPUT); digitalWrite(sda, LOW); } }
  void scl_out(bool val) { if(val) pinMode(scl, INPUT_PULLUP); else { pinMode(scl, OUTPUT); digitalWrite(scl, LOW); } }
  bool sda_in() { return digitalRead(sda); }
  void dly() { delayMicroseconds(2); } 

  void start() { sda_out(1); scl_out(1); dly(); sda_out(0); dly(); scl_out(0); dly(); }
  void stop()  { sda_out(0); scl_out(0); dly(); scl_out(1); dly(); sda_out(1); dly(); }
  
  bool write(uint8_t data) {
    for(int i=0; i<8; i++) {
      sda_out(data & 0x80); dly(); scl_out(1); dly(); scl_out(0); dly();
      data <<= 1;
    }
    sda_out(1); dly(); scl_out(1); dly();
    bool ack = !sda_in(); 
    scl_out(0); dly();
    return ack;
  }
  
  uint8_t read(bool ack) {
    uint8_t data = 0;
    sda_out(1); 
    for(int i=0; i<8; i++) {
      data <<= 1; dly(); scl_out(1); dly();
      if(sda_in()) data |= 1;
      scl_out(0); dly();
    }
    sda_out(!ack); 
    dly(); scl_out(1); dly(); scl_out(0); dly();
    sda_out(1);
    return data;
  }
};

MySoftI2C i2c0;
MySoftI2C i2c1;
// [NODE: I2C_INSTANCE_END]

// [NODE: AI_UART_INSTANCE_START]
// 实例化原生硬件串口用于接收 AI 小智指令 (RX=PC11, TX=PC10)
HardwareSerial Serial_AI(PC11, PC10); 
// [NODE: AI_UART_INSTANCE_END]

// [NODE: CUSTOM_SENSOR_START]
float last_calculated_angle[2] = {0, 0};

float track_angle(uint16_t raw_adc, int sensor_idx) {
  static uint16_t last_raw[2] = {0, 0};
  static int32_t full_rotations[2] = {0, 0};
  static bool first_read[2] = {true, true};

  if (first_read[sensor_idx]) {
    last_raw[sensor_idx] = raw_adc;
    first_read[sensor_idx] = false;
    last_calculated_angle[sensor_idx] = (raw_adc / 4096.0f) * _2PI;
    return last_calculated_angle[sensor_idx];
  }

  int16_t d_raw = raw_adc - last_raw[sensor_idx];

  if (abs(d_raw) > 300 && abs(d_raw) < 3796) {
    return last_calculated_angle[sensor_idx]; 
  }

  if (d_raw > 2048)       full_rotations[sensor_idx]--;
  else if (d_raw < -2048) full_rotations[sensor_idx]++;

  last_raw[sensor_idx] = raw_adc;
  last_calculated_angle[sensor_idx] = ((full_rotations[sensor_idx] * 4096) + raw_adc) / 4096.0f * _2PI;
  return last_calculated_angle[sensor_idx];
}

float readSensor0() {
  i2c0.start();
  if(!i2c0.write(0x36 << 1)) { i2c0.stop(); return last_calculated_angle[0]; } 
  if(!i2c0.write(0x0C))      { i2c0.stop(); return last_calculated_angle[0]; }
  i2c0.stop();
  i2c0.start();
  if(!i2c0.write((0x36 << 1) | 1)) { i2c0.stop(); return last_calculated_angle[0]; }
  uint8_t hi = i2c0.read(true);
  uint8_t lo = i2c0.read(false);
  i2c0.stop();
  
  // ★ 神级修复：高位寄存器头 4 位必然是 0。如果不为 0 (如0xFF)，绝对是断线乱码！一击必杀！
  if ((hi & 0xF0) != 0) return last_calculated_angle[0];

  return track_angle(((hi << 8) | lo) & 0x0FFF, 0);
}
void initSensor0() { i2c0.init(PB11, PB10); }
GenericSensor sensor0 = GenericSensor(readSensor0, initSensor0);

float readSensor1() {
  i2c1.start();
  if(!i2c1.write(0x36 << 1)) { i2c1.stop(); return last_calculated_angle[1]; }
  if(!i2c1.write(0x0C))      { i2c1.stop(); return last_calculated_angle[1]; }
  i2c1.stop();
  i2c1.start();
  if(!i2c1.write((0x36 << 1) | 1)) { i2c1.stop(); return last_calculated_angle[1]; }
  uint8_t hi = i2c1.read(true);
  uint8_t lo = i2c1.read(false);
  i2c1.stop();
  
  // ★ 同样为 M1 加上这层物理防弹衣
  if ((hi & 0xF0) != 0) return last_calculated_angle[1];

  return track_angle(((hi << 8) | lo) & 0x0FFF, 1);
}
void initSensor1() { i2c1.init(PB9, PB8); }
GenericSensor sensor1 = GenericSensor(readSensor1, initSensor1);
// [NODE: CUSTOM_SENSOR_END]

// [NODE: MOTOR_INSTANCE_START]
BLDCMotor motor0 = BLDCMotor(11); 
BLDCDriver3PWM driver0 = BLDCDriver3PWM(PA8, PA9, PA10, NOT_SET);  

BLDCMotor motor1 = BLDCMotor(11); 
BLDCDriver3PWM driver1 = BLDCDriver3PWM(PA0, PA1, PA2, NOT_SET);  
// [NODE: MOTOR_INSTANCE_END]

// [NODE: GLOBAL_VARIABLES_START]
LowPassFilter filter_yaw(0.02);   
LowPassFilter filter_pitch(0.02); 

uint8_t rx_buf[32]; 

float yaw_offset = 0;   
float pitch_offset = 0; 
bool first_data_received = false; 

float initial_motor0_angle = 0;
float initial_motor1_angle = 0;

// ================= AI 小智开火控制：新增全局状态 =================
// ESP32 AI 小智会通过 UART2 发来单字节：'F' 开火，'S' 停火。
// 为了防止停火字节丢失，炮塔端收到 'F' 后本地最多保持 3000ms，然后自动停火。
static const uint8_t FIRE_PIN = PA3;
static const uint32_t AI_FIRE_DURATION_MS = 3000;

bool ai_fire_active = false;
uint32_t ai_fire_deadline_ms = 0;

void StartAIFire() {
  ai_fire_active = true;
  ai_fire_deadline_ms = millis() + AI_FIRE_DURATION_MS;
  Serial.println("AI Command: FIRE for 3 seconds.");
}

void StopAIFire() {
  if (ai_fire_active) {
    Serial.println("AI Command: STOP.");
  }
  ai_fire_active = false;
}

void UpdateAIFireTimeout() {
  if (ai_fire_active && (int32_t)(millis() - ai_fire_deadline_ms) >= 0) {
    ai_fire_active = false;
    Serial.println("AI Fire timeout: auto stop.");
  }
}
// ================================================================
// [NODE: GLOBAL_VARIABLES_END]

void setup() {
  // [NODE: SYSTEM_INIT_START]
  Serial.setTx(PB6);
  Serial.setRx(PB7);
  Serial.begin(115200);
  delay(1500);
  Serial.println("\r\n--- V3P Turret System (AI Voice & RF Dual Control) ---");  

  // 初始化 AI 小智监听串口 (波特率必须与 ESP32 源码中的 115200 一致)
  Serial_AI.begin(115200);

  // 唤醒 V3P 驱动板
  pinMode(PB12, OUTPUT);
  digitalWrite(PB12, HIGH);

  // 初始化开火控制 MOS 管引脚 PA3，默认低电平停火
  pinMode(FIRE_PIN, OUTPUT);
  digitalWrite(FIRE_PIN, LOW);
  // [NODE: SYSTEM_INIT_END]

  // [NODE: NRF_INIT_START]
  NRF24L01_Pin_Init();
  if (NRF24L01_Check() == 0) {
    Serial.println("NRF24L01 detected successfully!");
  } else {
    Serial.println("WARNING: NRF24L01 NOT found!");
  }
  NRF24L01_RX_Init(); 
  Serial.println("NRF24L01 Listening...");
  // [NODE: NRF_INIT_END]

  // [NODE: SENSOR_INIT_START]
  sensor0.init();
  motor0.linkSensor(&sensor0);
  
  sensor1.init();
  motor1.linkSensor(&sensor1);  
  // [NODE: SENSOR_INIT_END]

  // [NODE: DRIVER_INIT_START]
  driver0.voltage_power_supply = 14.8; 
  driver0.init();
  motor0.linkDriver(&driver0);  

  driver1.voltage_power_supply = 14.8; 
  driver1.init();
  motor1.linkDriver(&driver1);  
  // [NODE: DRIVER_INIT_END]

   // [NODE: FOC_PARAMS_START]
  motor0.controller = MotionControlType::angle;
  motor1.controller = MotionControlType::angle;

  motor0.voltage_limit = 7.0;
  motor1.voltage_limit = 7.0;
  motor0.velocity_limit = 20.0;  
  motor1.velocity_limit = 20.0;  
  
  motor0.voltage_sensor_align = 4.0;
  motor1.voltage_sensor_align = 4.0;
  motor0.motion_downsample = 2; 
  motor1.motion_downsample = 2; 
  motor0.LPF_velocity.Tf = 0.05;
  motor1.LPF_velocity.Tf = 0.05;

  motor0.P_angle.P = 12.0;
  motor1.P_angle.P = 12.0;
  motor0.PID_velocity.P = 0.5;
  motor1.PID_velocity.P = 0.5;
  
  motor0.PID_velocity.I = 2.0;  
  motor1.PID_velocity.I = 2.0;  

  motor0.PID_velocity.output_ramp = 1000.0; 
  motor1.PID_velocity.output_ramp = 1000.0; 
  
  motor0.PID_velocity.limit = 7.0; 
  motor1.PID_velocity.limit = 7.0;
  // [NODE: FOC_PARAMS_END]

   // [NODE: FOC_CALIBRATION_START]
  motor0.init();
  motor1.init();
  
  motor0.zero_electric_angle = 0.1427;
  motor0.sensor_direction = Direction::CW;
  
  motor1.zero_electric_angle = 2.4360;
  motor1.sensor_direction = Direction::CW;

  Serial.println("Skipping Auto-Calibration, using saved values...");
  
  motor0.initFOC();  
  motor1.initFOC();  

  initial_motor0_angle = sensor0.getAngle();
  initial_motor1_angle = sensor1.getAngle();
  
  motor0.target = initial_motor0_angle;
  motor1.target = initial_motor1_angle;

  Serial.println("\r\nSystem Ready! Waiting for Head Tracker data...");
  // [NODE: FOC_CALIBRATION_END]
}  

void loop() {
    // 用于安全断电的失联时间戳
 
  // [NODE: LOOP_RATE_LIMITER_START]
  static uint32_t last_loop_time = 0;
  if (micros() - last_loop_time < 2500) return; 
  last_loop_time = micros();
  // [NODE: LOOP_RATE_LIMITER_END]

  // [NODE: NRF_RECEIVE_START]
  // ================= 1. 处理 AI 小智语音开火指令 =================
  // AI 小智现有源码中 SendTurretFire(true) 发送 'F'，3秒后发送 'S'。
  // 这里不再做“偏航轴转动10度”的测试动作，只控制 PA3 开火输出。
  while (Serial_AI.available()) {
      char c = Serial_AI.read();
      if (c == 0x46 || c == 'F') {      // 'F' = FIRE
          StartAIFire();
      } else if (c == 0x53 || c == 'S') { // 'S' = STOP
          StopAIFire();
      }
  }

  // 本地3秒自动停火保护：即使 AI 小智的 'S' 字节丢失，也不会一直开火
  UpdateAIFireTimeout();

  // ================= 2. 处理头瞄物理按键指令 =================
  static uint32_t last_valid_rx_time = 0; 
  static bool rf_fire_active = false; 

  if (digitalRead(PC6) == LOW) { 
    if (NRF24L01_RxPacket(rx_buf) == 0) {
      if (rx_buf[0] == 5) { 
        
        last_valid_rx_time = millis(); 

        int16_t raw_pitch = (rx_buf[1] << 8) | rx_buf[2];
        int16_t raw_yaw   = (rx_buf[3] << 8) | rx_buf[4];
        uint8_t fire_cmd  = rx_buf[5]; 
        
        float current_pitch = raw_pitch / 100.0f;
        float current_yaw   = raw_yaw / 100.0f;

        static float last_valid_pitch = 0;
        static float last_valid_yaw = 0;
        static int reject_count = 0; 
        bool valid_packet = true;

        if (!first_data_received) {
            pitch_offset = current_pitch;
            yaw_offset = current_yaw;
            last_valid_pitch = current_pitch;
            last_valid_yaw   = current_yaw;
            first_data_received = true;
            Serial.println("First Head Tracker data received! Turret Synced.");
        } else {
            if (abs(current_pitch - last_valid_pitch) > 30.0f || abs(current_yaw - last_valid_yaw) > 30.0f) {
                reject_count++;
                if (reject_count < 5) valid_packet = false;
            }
            if (valid_packet) {
                reject_count = 0;
                last_valid_pitch = current_pitch;
                last_valid_yaw   = current_yaw;
            }
        }

        if (valid_packet) {
            float target_pitch_rad = -(current_pitch - pitch_offset) * (PI / 180.0f);
            float target_yaw_rad   = -(current_yaw - yaw_offset) * (PI / 180.0f);

            float pitch_limit_deg = 25.0f; 
            float yaw_limit_deg   = 85.0f; 
            
            float pitch_limit_rad = pitch_limit_deg * (PI / 180.0f);
            float yaw_limit_rad   = yaw_limit_deg * (PI / 180.0f);

            target_pitch_rad = constrain(target_pitch_rad, -pitch_limit_rad, pitch_limit_rad);
            target_yaw_rad   = constrain(target_yaw_rad, -yaw_limit_rad, yaw_limit_rad);

            motor1.target = filter_pitch(target_pitch_rad) + initial_motor1_angle; 
            motor0.target = filter_yaw(target_yaw_rad) + initial_motor0_angle;   

            // 提取无线开火状态
            if (fire_cmd == 1) {
                rf_fire_active = true;
            } else {
                rf_fire_active = false;
            }
        }
      }
    }
  }

  // ================= 3. 完美融合判定与安全控制 =================
  if (millis() - last_valid_rx_time > 200) {
      rf_fire_active = false; // 失联保护，仅清除物理按键开火状态
  }

  // 只要有一个要求开火，MOS 管就导通
  if (ai_fire_active || rf_fire_active) {
      digitalWrite(FIRE_PIN, HIGH);
  } else {
      digitalWrite(FIRE_PIN, LOW);
  }
  // [NODE: NRF_RECEIVE_END]

  // [NODE: FOC_LOOP_START]
  // ★ 静态死区算法：误差小于 0.02 弧度时切断动力。调用官方 reset() 方法安全清空积分
  if (abs(motor0.target - sensor0.getAngle()) < 0.02) {
      motor0.voltage_limit = 0; 
      motor0.PID_velocity.reset(); 
  } else {
      motor0.voltage_limit = 7.0; 
  }

  if (abs(motor1.target - sensor1.getAngle()) < 0.02) {
      motor1.voltage_limit = 0; 
      motor1.PID_velocity.reset(); 
  } else {
      motor1.voltage_limit = 7.0; 
  }

  motor0.loopFOC();
  motor0.move();  
  motor1.loopFOC();
  motor1.move();  
  // [NODE: FOC_LOOP_END]
}

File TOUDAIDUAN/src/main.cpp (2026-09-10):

#include <Arduino.h>
#include <Wire.h>
#include "ICM_20948.h"
#include "nRF24L01_API.h" // 引入无线通信模块头文件

HardwareSerial Serial1(PA10, PA9);

#define AD0_VAL 0 
ICM_20948_I2C myICM;

// NRF24L01 发送缓冲区 (最大32字节)
uint8_t rece_buf[32]; 

void setup() {
    // 初始化发射按钮，使用内部下拉电阻！
  pinMode(PB12, INPUT_PULLDOWN);
  Serial1.begin(115200);
  delay(2000); 
  Serial1.println("\r\n====================================");
  Serial1.println("--- STM32 Head Tracker (Remapped Axis) ---");

  // ================= 1. 初始化 NRF24L01 =================
  Serial1.println("Initializing NRF24L01...");
  NRF24L01_Pin_Init();
  
  if (NRF24L01_Check() == 0) {
    Serial1.println("NRF24L01 detected successfully!");
  } else {
    Serial1.println("NRF24L01 NOT found! Check SPI wiring.");
  }
  
  // 配置为 2Mbps 且无自动应答的极限低延迟单向模式
  NRF24L01_RT_Init(); 

  // ================= 2. 初始化 I2C 与 陀螺仪 =================
  Wire.setSCL(PB6);
  Wire.setSDA(PB7);
  Wire.begin(); 
  Wire.setClock(100000); // 100kHz 稳定模式
  Serial1.println("I2C configured. Initializing ICM20948...");

  bool initialized = false;
  while (!initialized) {
    myICM.begin(Wire, AD0_VAL);
    if (myICM.status != ICM_20948_Stat_Ok) {
      Serial1.println("ICM20948 not detected! Please check wiring.");
      delay(1000);
    } else {
      initialized = true;
      Serial1.println("ICM20948 detected! Loading DMP Firmware...");
    }
  }

  // ================= 3. 启动 DMP =================
  bool success = true;
  success &= (myICM.initializeDMP() == ICM_20948_Stat_Ok);
  success &= (myICM.enableDMPSensor(INV_ICM20948_SENSOR_GAME_ROTATION_VECTOR) == ICM_20948_Stat_Ok);
  success &= (myICM.setDMPODRrate(DMP_ODR_Reg_Quat6, 0) == ICM_20948_Stat_Ok);
  success &= (myICM.enableFIFO() == ICM_20948_Stat_Ok);
  success &= (myICM.enableDMP() == ICM_20948_Stat_Ok);
  success &= (myICM.resetDMP() == ICM_20948_Stat_Ok);
  success &= (myICM.resetFIFO() == ICM_20948_Stat_Ok);

  if (success) {
    Serial1.println("DMP initialized successfully! System is LIVE!");
  } else {
    Serial1.println("DMP initialization failed! System halted.");
    while(1); 
  }
}

void loop() {
  icm_20948_DMP_data_t data;
  myICM.readDMPdataFromFIFO(&data);

  // 记录初始零点的静态变量
  static bool is_zero_recorded = false;
  static uint32_t dmp_start_time = 0; 
  static double initial_pitch = 0.0;
  static double initial_roll  = 0.0;
  static double initial_yaw   = 0.0;

  if ((myICM.status == ICM_20948_Stat_Ok) || (myICM.status == ICM_20948_Stat_FIFOMoreDataAvail)) {
    
    // 确认读到的是 6轴四元数 数据
    if ((data.header & DMP_header_bitmap_Quat6) > 0) {
      
      // 1. 读取物理传感器的原始四元数数据
      // 你的新安装位置：X(右), Y(前), Z(上)
      double raw_q1 = ((double)data.Quat6.Data.Q1) / 1073741824.0; // 物理 X
      double raw_q2 = ((double)data.Quat6.Data.Q2) / 1073741824.0; // 物理 Y
      double raw_q3 = ((double)data.Quat6.Data.Q3) / 1073741824.0; // 物理 Z

      // 2. 坐标轴重映射
      // 目标标准数学模型必须是：X(前)，Y(左)，Z(上)
      double q1 =  raw_q2;   // 数学 X(前) = 物理 Y(前)
      double q2 = -raw_q1;   // 数学 Y(左) = -物理 X(右)
      double q3 =  raw_q3;   // 数学 Z(上) = 物理 Z(上)
      
      double q0 = sqrt(1.0 - ((q1 * q1) + (q2 * q2) + (q3 * q3)));

      // 3. 计算绝对欧拉角 (此时 Yaw 和 Roll 的串轴已经被修复！)
      double abs_pitch = asin(2.0 * (q0 * q2 - q1 * q3)) * 180.0 / PI;
      double abs_roll  = atan2(2.0 * (q0 * q1 + q2 * q3), 1.0 - 2.0 * (q1 * q1 + q2 * q2)) * 180.0 / PI;
      double abs_yaw   = atan2(2.0 * (q0 * q3 + q1 * q2), 1.0 - 2.0 * (q2 * q2 + q3 * q3)) * 180.0 / PI;

      // 满足你的要求：抬头 Pitch 增加 (翻转 Pitch 的正负方向)
      abs_pitch = -abs_pitch; 

      // 记录 DMP 首次输出数据的时间
      if (dmp_start_time == 0) dmp_start_time = millis();

      // 4. 等待 DMP 完全收敛 (8 秒) 后捕捉绝对零点
      if (!is_zero_recorded) {
        if (millis() - dmp_start_time < 8000) { 
          static uint32_t last_dot_time = 0;
          if (millis() - last_dot_time > 1000) {
             Serial1.print("Warming up DMP... ");
             Serial1.print(8 - (millis() - dmp_start_time)/1000);
             Serial1.println(" seconds left");
             last_dot_time = millis();
          }
          return; 
        } else {
          initial_pitch = abs_pitch;
          initial_roll  = abs_roll;
          initial_yaw   = abs_yaw;
          is_zero_recorded = true;
          Serial1.println("\r\n[DMP Converged! Zero Point Recorded!]");
        }
      }

      // 5. 零点捕捉完毕，输出干净的相对角度
      if (is_zero_recorded) {
        // ========== 修复了之前的乱码截断部分 ==========
        double pitch = abs_pitch - initial_pitch;
        double roll  = abs_roll  - initial_roll;
        double yaw   = abs_yaw   - initial_yaw;

        // 防止转圈时角度溢出（规范在 ±180 度以内）
        if (yaw > 180.0) yaw -= 360.0;   else if (yaw < -180.0) yaw += 360.0;
        if (pitch > 180.0) pitch -= 360.0; else if (pitch < -180.0) pitch += 360.0;
        if (roll > 180.0) roll -= 360.0;   else if (roll < -180.0) roll += 360.0;

        // 串口直观调试输出
        Serial1.print("Pitch:"); Serial1.print(pitch);
        Serial1.print("\tRoll:"); Serial1.print(roll);
        Serial1.print("\tYaw:"); Serial1.println(yaw);

      
      
            // ================= 数据打包发送 =================
      int16_t send_pitch = (int16_t)(pitch * 100);
      int16_t send_yaw   = (int16_t)(yaw * 100);

      // ★ 读取开火按键状态：因为是下拉，按下连通 3.3V 时为 HIGH (1)
      uint8_t fire_command = (digitalRead(PB12) == HIGH) ? 1 : 0;

      rece_buf[0] = 5; // ★ 数据长度变为 5
      rece_buf[1] = (send_pitch >> 8) & 0xFF; 
      rece_buf[2] = send_pitch & 0xFF;        
      rece_buf[3] = (send_yaw >> 8) & 0xFF;   
      rece_buf[4] = send_yaw & 0xFF;          
      rece_buf[5] = fire_command; // ★ 第5个字节装填开火指令

      SEND_BUF(rece_buf); 
       
        // ==========================================
      }
    }
  }
}
